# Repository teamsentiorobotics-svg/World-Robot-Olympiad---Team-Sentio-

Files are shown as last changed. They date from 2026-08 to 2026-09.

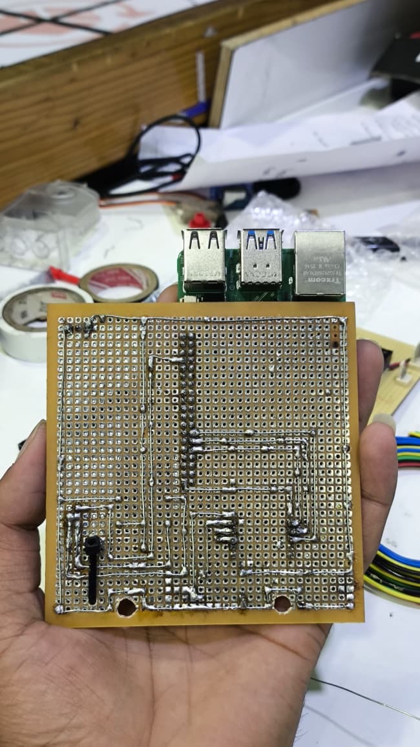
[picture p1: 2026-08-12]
v-photos/solder view of circuit board.jpg

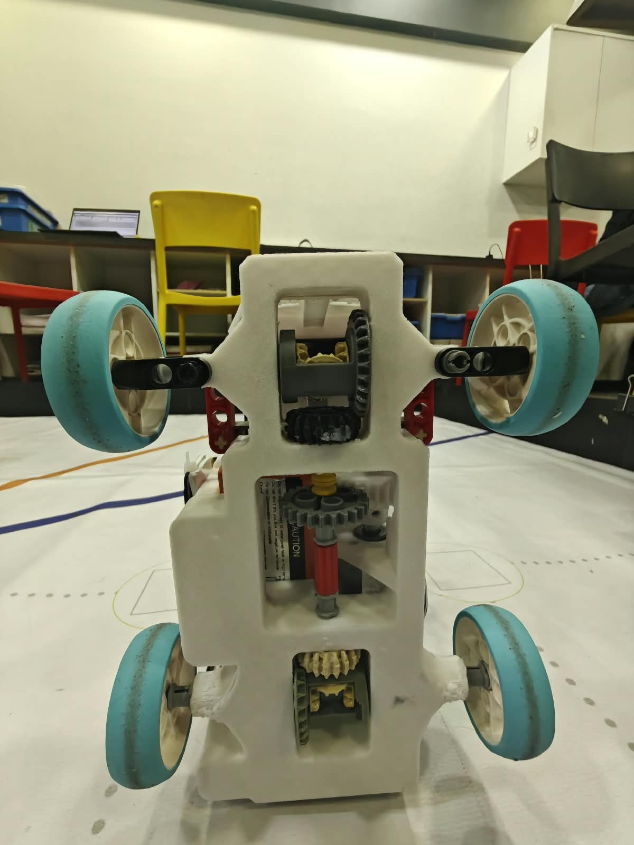
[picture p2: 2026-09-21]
v-photos/bottom view (1).jpg

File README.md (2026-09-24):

# Team Sentio - WRO Future Engineers 2026

> **Starlight**  
> Autonomous vehicle developed by **Team Sentio** for the **World Robot Olympiad 2026 - Future Engineers** category.

**Team:** Deyaan Agrawal, Darsh Zaveri, Aarav Jalan  
**Mentors:** Sunil Solanki, Shyam Satasiya  
**Institution / Training Environment:** Robofun Lab (RFL), India  
**Robot:** Starlight  
**Competition:** World Robot Olympiad 2026 - Future Engineers  
**Current Documentation Revision:** Revision 29, 23 September 2026

---

# Engineering Philosophy

Starlight was not developed as one finished design.

The vehicle evolved through repeated mechanical, electrical, sensing and software revisions.

Our development process follows:

> **Build → Test → Observe → Find the failure → Modify → Retest**

The current system combines:

- four-wheel drive;
- front Ackermann steering;
- a mechanical differential;
- dual Raspberry Pi Camera Module 3 Wide cameras;
- multi-ROI computer vision;
- HSV + LAB colour processing;
- an MPU6050 relative-heading reference;
- motor-encoder feedback;
- three VL53L0X time-of-flight sensors;
- modular Open, Obstacle and Parking controllers;
- Raspberry Pi 5 processing;
- field calibration and dedicated subsystem-test programs.

The project is documented as an integrated engineering system rather than as a collection of independent components.

---

# Repository Structure

```text
.
├── README.md
├── CHANGELOG.md
├── requirements.md
├── .gitattributes
├── .gitignore
│
├── src/
│   ├── Cal_APOC.py
│   ├── Final_Obstacle_Challenge.py
│   ├── N_Vision_final.py
│   ├── Sentio_Open_2026.py
│   ├── openvision.py
│   ├── TOF_22.py
│   ├── TUF_test.py
│   ├── drive.py
│   ├── encoder_test.py
│   ├── heading.py
│   ├── parking_final.py
│   └── servo_test.py
│
├── Models/
│
├── docs/
│   ├── BOM_purchase_links.md
│   ├── wiring_guide.md
│   ├── differential_drive_system.md
│   ├── Software_Dependencies.md
│   ├── pi_setup_instruction.md
│   │
│   ├── development/
│   │   └── apoc-hardware-update.md
│   │
│   ├── engineering_decisions/
│   ├── software/
│   ├── testing/
│   ├── failure_log.md
│   └── readme.md
│
├── schemes/
├── v-photos/
├── t-photos/
├── videos/
└── other/
```

| Location | Purpose |
|---|---|
| `src/` | Competition controllers, sensing modules, calibration tools and component tests |
| `Models/` | Chassis, robot-design and printable STL/CAD resources |
| `docs/` | Engineering decisions, testing records, BOM, wiring, dependencies and setup |
| `schemes/` | Electrical and wiring references |
| `v-photos/` | Vehicle photographs |
| `t-photos/` | Team photographs |
| `videos/` | Physical autonomous-driving evidence |
| `other/` | Supporting engineering, testing and planning material |
| `README.md` | Main repository-level project overview |
| `CHANGELOG.md` | Dated development history |
| `requirements.md` | Software dependency record |

---

# 1. System Overview

Starlight is a compact four-wheel autonomous vehicle designed around **car-like steering mechanics, camera-led navigation and multiple complementary sensors**.

The current configuration combines several different observations:

```text
CAMERAS
   ↓
Walls, pillars, track geometry and colour cues

MPU6050
   ↓
Relative heading and orientation change

MOTOR ENCODER
   ↓
Shaft rotation and movement feedback

3 × VL53L0X
   ↓
Short-range distance information

          ↓

     RASPBERRY PI 5

          ↓

Navigation state
Steering
Propulsion

          ↓

4WD + ACKERMANN STEERING
```

Each sensor answers a different question.

The software does not treat one sensor as an exact replacement for another.

---

# 2. Current Mechanical Architecture

The current vehicle uses:

- four-wheel drive;
- front Ackermann steering;
- a mechanical differential;
- custom structural components;
- LEGO Technic drivetrain and mechanism elements where appropriate;
- rigid camera supports;
- rigid distance-sensor mounts;
- a geared DC drive motor;
- quadrature encoder feedback.

The mechanical structure must do more than simply hold the robot together.

It must keep the following sufficiently repeatable:

- camera geometry;
- sensor direction;
- drivetrain alignment;
- steering geometry;
- electronics placement;
- mechanical clearances.

---

## Ackermann Steering

Starlight turns like a small car.

During a turn:

- the inside front wheel follows a smaller-radius path;
- the outside front wheel follows a larger-radius path;
- the inside wheel therefore requires a larger steering angle.

Ackermann geometry allows the two front wheels to approximately follow their respective turning paths rather than forcing them through identical angles.

This reduces tyre scrub and improves repeatability during curved motion.

---

## Mechanical Differential

Steering angle and driven-wheel speed solve different problems.

The outside driven wheel travels farther than the inside driven wheel during a turn.

The mechanical differential allows the two sides of the drivetrain to rotate at different speeds while remaining powered through the same transmission.

```text
ACKERMANN STEERING
→ sets wheel direction

MECHANICAL DIFFERENTIAL
→ permits unequal driven-wheel speeds
```

Both contribute to smoother car-like turning.

---

# 3. Drivetrain

The current drivetrain uses a:

```text
12 V geared DC encoder motor
Nominal output speed: 600 RPM
External gear ratio: 1:1
```

The final transmission intentionally uses a **1:1 external ratio**.

This replaced an earlier speed-increasing drivetrain configuration.

The revised design gives greater priority to:

- usable wheel torque;
- drivetrain reliability;
- controllable movement;
- reduced motor loading;
- repeatable challenge behaviour.

A nominal motor RPM is a component specification.

It should not automatically be interpreted as measured vehicle ground speed.

---

## Four-Wheel Drive

Motor rotation is transferred through the mechanical drivetrain to all four wheels.

Four-wheel drive was retained because it provides:

- improved traction;
- more consistent propulsion;
- better load distribution;
- greater reliability during steering and obstacle manoeuvres.

---

## Motor Encoder

The drive motor includes a quadrature encoder.

The encoder reports shaft motion and direction through pulses.

It is used for:

- movement feedback;
- drivetrain testing;
- encoder-controlled movement requests;
- checking motor response;
- repeatable motion during selected manoeuvres.

Encoder rotation is not identical to physical vehicle displacement.

Wheel slip, tyre deformation, drivetrain play and surface conditions can all cause body movement to differ from shaft-based estimates.

---

# 4. Main Electronics

The main computing platform is:

```text
Raspberry Pi 5
4 GB RAM
```

Current major hardware includes:

| Qty. | Component | Function |
|---:|---|---|
| 1 | Raspberry Pi 5, 4 GB | Main computer |
| 2 | Raspberry Pi Camera Module 3 Wide | Track and parking perception |
| 3 | VL53L0X ToF sensors | Short-range distance sensing |
| 1 | 12 V geared DC encoder motor, 600 RPM | Propulsion |
| 1 | Integrated quadrature encoder | Shaft-motion feedback |
| 1 | TB6612FNG motor driver | Motor direction and PWM |
| 1 | DS3225 digital servo | Ackermann steering |
| 1 | MPU6050-based heading sensor | Relative angular motion |
| 1 | 3S LiPo battery | Main energy source |
| 1 | Regulated Raspberry Pi supply | Computer power |
| 1 | Start button | Physical run input |
| 1 | Status / illumination LED | Indication and illumination |

---

# 5. Power System

Main battery:

```text
3S LiPo
11.1 V nominal
2200 mAh
```

Nominal stored energy:

```text
11.1 V × 2.2 Ah
≈ 24.42 Wh
```

Starlight separates the major electrical loads into functional branches.

```text
               BATTERY
                  │
         ┌────────┴────────┐
         │                 │
     MOTOR RAIL       REGULATED RAIL
         │                 │
   Motor driver        Raspberry Pi
   Drive motor         Cameras
                       Sensors
```

Connected control electronics share an appropriate common electrical reference.

Voltage stability is important because motor starts, motor reversals and servo movements can produce rapidly changing current demand.

---

# 6. GPIO and Interfaces

Main Raspberry Pi control assignments include:

| Function | BCM GPIO |
|---|---:|
| Motor IN1 | GPIO5 |
| Motor IN2 | GPIO6 |
| Motor PWM | GPIO13 |
| Steering servo | GPIO22 |
| Encoder A | GPIO17 |
| Encoder B | GPIO27 |
| I2C SDA | GPIO2 |
| I2C SCL | GPIO3 |
| ToF 1 XSHUT | GPIO16 |
| ToF 2 XSHUT | GPIO20 |
| ToF 3 XSHUT | GPIO21 |

The MPU6050 uses the shared I2C bus.

The three VL53L0X sensors also communicate over I2C.

Because identical VL53L0X sensors initially use the same default address, their XSHUT lines allow them to be enabled sequentially and assigned separate working addresses.

---

# 7. Camera Architecture

Starlight uses:

```text
2 × Raspberry Pi Camera Module 3 Wide
```

The camera arrangement is designed to observe the useful portion of the track while allowing different image regions to perform different tasks.

The documented viewing direction is approximately:

```text
60° from horizontal
```

The relatively downward-facing view prioritizes:

- nearby walls;
- pillar bases;
- track markers;
- parking geometry;
- immediate steering information.

The trade-off is reduced distant look-ahead and stronger perspective effects.

---

# 8. Multi-ROI Computer Vision

The current primary vision architecture uses a **720 × 360 image** divided into task-specific regions of interest.

A simplified representation is:

```text
┌──────────────────────────────────────────────┐
│ L1        L2        C        R2        R1    │
│                                              │
│            ORANGE / BLUE REGION              │
│                                              │
│              BODY EXCLUSION                  │
└──────────────────────────────────────────────┘
```

Different regions answer different navigation questions.

Responsibilities include:

- outer-wall observation;
- inner-wall observation;
- center reference;
- orange / blue course cues;
- pillar detection;
- robot-body exclusion.

The robot's own structure may appear dark in the camera image.

Body-exclusion regions prevent visible parts of the vehicle from being interpreted as track walls.

---

# 9. Vision Processing

The primary obstacle vision module is:

```text
src/N_Vision_final.py
```

The processing pipeline can be summarized as:

```text
Camera frame
     ↓
HSV / LAB conversion
     ↓
Task-specific ROI selection
     ↓
Colour / darkness thresholding
     ↓
Morphological filtering
     ↓
Contour extraction
     ↓
Area and geometry filtering
     ↓
Region-aware detection
     ↓
Navigation observation
```

The system uses combinations of:

- HSV colour information;
- LAB colour information;
- darkness information;
- contour size;
- contour geometry;
- image position;
- ROI identity.

Navigation therefore does not depend solely on whether a handful of pixels happen to match a colour threshold.

---

# 10. Calibration

Field lighting can substantially change the appearance of the same physical colour.

The repository therefore includes:

```text
src/Cal_APOC.py
```

This provides interactive LAB / HSV calibration controls.

Calibration is used to tune colour ranges for the actual competition environment before relying on those thresholds for autonomous navigation.

Calibration should be checked after changes involving:

- field lighting;
- camera position;
- camera angle;
- exposure;
- track material;
- major mechanical reconstruction.

---

# 11. Software Architecture

The competition software is divided into mission-level controllers and reusable hardware or sensing modules.

```text
                    VISION MODULES
                         │
             ┌───────────┴───────────┐
             │                       │
     Open Challenge           Obstacle Challenge
             │                       │
 Sentio_Open_2026.py     Final_Obstacle_Challenge.py
             │                       │
       openvision.py          N_Vision_final.py
             │                       │
             └───────────┬───────────┘
                         │
                  parking_final.py
                         │
                     heading.py
                         │
                      drive.py
                         │
               Motor + encoder
                 + steering
```

Distance-sensor support is provided through:

```text
TOF_22.py
```

This modular structure makes faults easier to isolate.

A poor autonomous turn may originate from:

- perception;
- target selection;
- heading estimation;
- steering;
- drivetrain response;
- state logic.

Separating these responsibilities allows individual layers to be tested before a complete challenge run.

---

# 12. Open Challenge

The current Open Challenge controller is:

```text
src/Sentio_Open_2026.py
```

Its dedicated vision module is:

```text
src/openvision.py
```

---

## Open Challenge Strategy

The Open Challenge primarily uses continuous wall-relative correction.

```text
Observe walls + course markers
            ↓
Determine course direction
            ↓
Select active wall reference
            ↓
Calculate image error
            ↓
Apply proportional steering
            ↓
Move
            ↓
Detect valid course event
            ↓
Repeat
```

A general proportional relationship is:

```text
steering request
=
center request
+
KP × image error
```

The controller repeatedly updates the steering response as camera observations change.

This differs from relying entirely on predetermined timed turns.

---

## Course Direction

Course direction affects:

- wall selection;
- target image position;
- fallback behaviour;
- obstacle context;
- parking approach.

---

## Course Event Counting

A physical marker can remain visible across many consecutive camera frames.

The controller therefore distinguishes:

```text
NEW EVENT
```

from:

```text
SAME EVENT STILL VISIBLE
```

Cooldown and transition logic prevent the same marker from being repeatedly counted simply because it remains visible.

---

# 13. Obstacle Challenge

The main controller is:

```text
src/Final_Obstacle_Challenge.py
```

The Obstacle Challenge combines:

- wall geometry;
- red pillar detection;
- green pillar detection;
- course direction;
- heading feedback;
- encoder-assisted movement;
- orange course-event counting;
- parking transition logic;
- repeated visual observations.

---

## Obstacle Selection

Red and green objects are treated as different navigation targets.

The controller considers:

- object colour;
- object position;
- bounding-box geometry;
- region identity;
- active manoeuvre;
- course direction.

A pillar becoming visible does not automatically mean that the robot should abandon an active manoeuvre.

This is especially important near corners, where a new observation may appear before the previous turn is complete.

---

## Continuous Perception

The obstacle architecture repeatedly returns to sensing.

```text
OBSERVE
   ↓
SELECT RELEVANT FEATURE
   ↓
CHOOSE ACTIVE CONTROL STATE
   ↓
STEER / MOVE
   ↓
OBSERVE AGAIN
```

The changing camera view is therefore part of the feedback loop.

---

# 14. MPU6050 Heading

Shared heading logic is contained in:

```text
src/heading.py
```

The heading module:

1. initializes communication with the MPU6050;
2. measures stationary gyro bias;
3. subtracts the estimated bias;
4. reads angular velocity;
5. integrates angular velocity over elapsed time;
6. maintains a relative heading estimate.

Conceptually:

```text
relative heading
=
previous heading
+
corrected angular velocity × elapsed time
```

The result is a **relative orientation estimate**.

It is not treated as an exact global compass or position measurement.

---

## Why Heading Feedback Is Useful

A fixed motor time does not always produce the same turn.

Variation can result from:

- battery condition;
- motor loading;
- tyre contact;
- friction;
- drivetrain resistance;
- surface conditions.

Heading feedback allows selected manoeuvres to finish according to the robot's observed orientation rather than time alone.

---

# 15. Parking

The parking controller is:

```text
src/parking_final.py
```

Parking combines:

- camera geometry;
- magenta parking references;
- wall observations;
- heading feedback;
- three VL53L0X distance sensors;
- forward and reverse Ackermann arcs;
- distance-confirmed stopping.

---

## Parking Objective

The final objective is to stop with the vehicle aligned **parallel to the magenta wall**.

Starlight cannot rotate about its center like a differential-drive robot.

Parking therefore requires controlled forward and reverse arcs.

---

## Parking Sequence

```text
COURSE COMPLETE
       ↓
IDENTIFY APPROACH DIRECTION
       ↓
POSITION VEHICLE
       ↓
ALIGN USING STEERING + HEADING
       ↓
READ SHORT-RANGE DISTANCE
       ↓
CONFIRM DISTANCE CONDITION
       ↓
FORWARD / REVERSE ADJUSTMENT
       ↓
FINAL PARALLEL ALIGNMENT
       ↓
STOP
```

The range sensors complement the camera and heading system.

They do not replace them.

```text
CAMERA
→ Where is the feature?

HEADING
→ Which direction is the robot pointing?

ToF
→ How large is the nearby gap?

ENCODER
→ How much shaft movement occurred?
```

---

# 16. ToF Distance Sensing

The current vehicle uses:

```text
3 × VL53L0X
```

The main distance-sensor support module is:

```text
src/TOF_22.py
```

The repository also includes:

```text
src/TUF_test.py
```

for standalone sensor testing.

The distance-sensor system supports:

- XSHUT activation sequencing;
- unique I2C addressing;
- repeated distance measurements;
- qualifying-distance thresholds;
- confirmation instead of trusting one isolated reading;
- cooldown between qualifying detections;
- range-based movement termination;
- parking alignment and clearance checks.

---

# 17. Clockwise and Anticlockwise Parking

The two possible course directions require different paths into the parking area.

```text
                    COURSE COMPLETE
                          │
                 Determine direction
                    ┌─────┴─────┐
                    │           │
                   CW          ACW
                    │           │
          CW entry position   Reposition
                    │           │
                    │       Follow wall
                    │           │
                    │     Opposite corner
                    └─────┬─────┘
                          │
                Shared final parking
                          │
               Parallel to magenta wall
                          │
                         STOP
```

The anticlockwise path performs the required repositioning before joining the final parking sequence.

---

# 18. Component Test Programs

Full challenge runs are not the first debugging step.

The repository contains dedicated subsystem tests.

---

## Steering Test

```text
src/servo_test.py
```

Used to verify:

- steering direction;
- center position;
- steering range;
- mechanical clearance;
- linkage behaviour.

---

## Encoder Test

```text
src/encoder_test.py
```

Used to verify:

- encoder pulse response;
- direction;
- motor movement;
- encoder-based drive control.

---

## Distance Sensor Test

```text
src/TUF_test.py
```

Used to verify:

- VL53L0X initialization;
- XSHUT sequencing;
- unique sensor addressing;
- distance readings;
- sensor orientation.

---

## Vision Calibration

```text
src/Cal_APOC.py
```

Used to tune:

- HSV thresholds;
- LAB thresholds;
- field colour appearance.

---

# 19. Testing Workflow

Team Sentio uses a layered validation process.

```text
COMPONENT TEST
      ↓
SUBSYSTEM TEST
      ↓
LOW-SPEED INTEGRATED TEST
      ↓
FULL CHALLENGE RUN
      ↓
OBSERVE FAILURE
      ↓
IDENTIFY RESPONSIBLE LAYER
      ↓
MODIFY
      ↓
RETEST
```

Before a complete autonomous run, checks include:

- battery state;
- electrical connections;
- regulated Raspberry Pi supply;
- common electrical reference;
- motor direction;
- drivetrain freedom;
- gear engagement;
- steering linkage;
- steering limits;
- encoder response;
- camera operation;
- vision calibration;
- MPU6050 communication;
- ToF communication;
- ToF sensor orientation;
- correct source-code revision.

---

# 20. Physical Timing Records

The engineering record retains successful-run timing observations from development and practice.

```text
Development cohort: 19 successful runs
Practice cohort:    12 successful runs
```

| Cohort | n | Mean | Median | SD | Range |
|---|---:|---:|---:|---:|---:|
| Development | 19 | 25.05 s | 23 s | 5.74 s | 18-37 s |
| Practice | 12 | 23.00 s | 23 s | 1.28 s | 21-25 s |

These are **successful retained runs only**.

They are not presented as the success rate of all attempted runs.

Different runs also belong to changing development configurations, so these timings should not be interpreted as a controlled comparison of one isolated design change.

---

# 21. Nationals Competition Record

The Nationals results belong to an **earlier competition configuration** and should not be interpreted as measurements of the current post-Nationals APOC revision.

| Round | Recorded Score | Recorded Time | Recorded Outcome |
|---|---:|---:|---|
| Open Run 1 | 0 / 30 | - | Inner-wall contact interrupted run |
| Open Run 2 | 30 / 30 | 56 s | Completed clockwise course |
| Obstacle Run 2 | 29 / 62 | 66 s to stop | Green-obstacle contact, parking not achieved |

These competition outcomes influenced later redesign of:

- camera geometry;
- vision regions;
- drivetrain;
- sensing;
- obstacle behaviour;
- parking logic.

---

# 22. Post-Nationals / APOC Redesign

The September 2026 configuration is a new engineering revision rather than a retroactive description of the Nationals vehicle.

Major changes include:

- revised chassis;
- revised camera placement;
- rigid sensing geometry;
- dual Camera Module 3 Wide architecture;
- multi-ROI vision;
- explicit body-exclusion regions;
- LAB / HSV calibration tools;
- revised wall detection;
- revised pillar detection;
- revised Open Challenge controller;
- revised Obstacle Challenge controller;
- three VL53L0X distance sensors;
- encoder-assisted movement;
- revised parking-distance logic;
- 600 RPM motor;
- 1:1 external drivetrain ratio.

---

# 23. Important Engineering Decisions

| Engineering Decision | Reason |
|---|---|
| Four-wheel drive | Improved propulsion consistency and traction |
| Ackermann steering | Car-like turning geometry |
| Mechanical differential | Allows unequal driven-wheel speeds during turns |
| 600 RPM encoder motor | Balance of movement, torque and controllability |
| 1:1 external gearing | Retains more wheel torque than the earlier speed-increasing stage |
| Rigid camera supports | More repeatable visual geometry |
| Approx. 60° camera view | Emphasizes nearby track features |
| Multi-ROI vision | Gives different image regions specific jobs |
| Body exclusion | Prevents the robot from detecting itself as a wall |
| HSV + LAB calibration | Field-specific colour adjustment |
| MPU6050 heading | Orientation-sensitive manoeuvre feedback |
| Encoder feedback | Shaft-motion information |
| Three VL53L0X sensors | Close-range gap and parking information |
| Modular software | Easier debugging and replacement of subsystems |
| Component-test scripts | Fault isolation before complete autonomous runs |

---

# 24. CAD and Mechanical Files

Mechanical-design resources are stored in:

```text
Models/
```

The directory contains available Starlight CAD, printable and mechanical-design resources.

Earlier CAD and prototype material is intentionally retained where useful for documenting the development process.

Earlier models should not automatically be interpreted as the exact geometry of the current robot.

---

# 25. Electrical Documentation

Electrical and wiring information is contained primarily in:

```text
docs/
schemes/
```

Important documents include:

```text
docs/BOM_purchase_links.md
docs/wiring_guide.md
docs/Software_Dependencies.md
docs/pi_setup_instruction.md
```

Together these document:

```text
COMPONENTS
     +
POWER / SIGNAL CONNECTIONS
     +
GPIO ASSIGNMENTS
     +
SOFTWARE CONTROL
```

A reproducible robot requires all four.

---

# 26. Engineering Development Records

The repository also preserves development evidence.

Relevant areas include:

```text
docs/development/
docs/engineering_decisions/
docs/testing/
docs/failure_log.md
CHANGELOG.md
```

These records document:

- hardware changes;
- observed failures;
- diagnoses;
- design decisions;
- corrective changes;
- retesting;
- configuration evolution.

The objective is to preserve not only what worked, but also **why the final design became different from earlier versions**.

---

# 27. Raspberry Pi Setup

Detailed setup information is provided through:

```text
docs/pi_setup_instruction.md
docs/Software_Dependencies.md
requirements.md
```

The software stack includes technologies such as:

- Python 3;
- OpenCV;
- NumPy;
- Picamera2;
- Raspberry Pi GPIO support;
- I2C / SMBus interfaces;
- GPIO Zero where required;
- sensor-specific Python libraries used by the robot.

The environment should be prepared before attempting to run competition controllers.

---

# 28. Recommended Reproduction Workflow

```text
1. Review README.md
        ↓
2. Review BOM and wiring
        ↓
3. Review Models/
        ↓
4. Assemble mechanical system
        ↓
5. Install Raspberry Pi environment
        ↓
6. Connect electronics
        ↓
7. Verify steering
        ↓
8. Verify motor + encoder
        ↓
9. Verify cameras
        ↓
10. Verify MPU6050
        ↓
11. Verify all VL53L0X sensors
        ↓
12. Calibrate vision
        ↓
13. Run low-speed integration
        ↓
14. Run challenge controller
        ↓
15. Record software + hardware revision
```

A challenge result should remain associated with the exact:

- hardware arrangement;
- camera geometry;
- calibration;
- software revision;
- observed result.

---

# 29. Current Competition Software

```text
src/
├── Cal_APOC.py
├── Final_Obstacle_Challenge.py
├── N_Vision_final.py
├── Sentio_Open_2026.py
├── openvision.py
├── TOF_22.py
├── TUF_test.py
├── drive.py
├── encoder_test.py
├── heading.py
├── parking_final.py
└── servo_test.py
```

### `Cal_APOC.py`

Interactive LAB / HSV field-calibration tool.

### `Final_Obstacle_Challenge.py`

Main Obstacle Challenge controller.

### `N_Vision_final.py`

Final multi-ROI computer vision for walls, pillars and track colours.

### `Sentio_Open_2026.py`

Main Open Challenge controller.

### `openvision.py`

Dedicated Open Challenge vision module.

### `TOF_22.py`

Three-sensor VL53L0X initialization and distance interface.

### `TUF_test.py`

Distance-sensor test program.

### `drive.py`

Motor, encoder and steering interface.

### `encoder_test.py`

Encoder and motor-control test program.

### `heading.py`

Shared MPU6050 relative-heading estimator.

### `parking_final.py`

Direction-dependent parking and final parking control.

### `servo_test.py`

Steering direction, center and range testing.

---

# 30. Development History

Starlight progressed through multiple complete vehicle configurations.

| Stage | Main Development |
|---|---|
| Early LEGO platform | Wheel motion, steering and basic structure |
| Hybrid construction | LEGO mechanisms combined with printed supports |
| Nationals configuration | Integrated navigation, obstacle response and parking |
| Post-Nationals redesign | New chassis, camera geometry, vision regions and sensing |
| Current APOC configuration | Multi-ROI perception, encoder feedback and three-ToF architecture |

The important point is that improvements were not isolated.

Changing one subsystem changed the conditions faced by others.

```text
CAMERA POSITION
→ changes image geometry

MOTOR / GEARING
→ changes movement response

STEERING
→ changes the path produced by the same command

POWER
→ changes computer and actuator reliability

SOFTWARE
→ must respond to all of the above
```

The robot therefore evolved as a complete system.

---

# 31. Team Contributions

## Deyaan Agrawal

Primary areas included:

- software;
- autonomous algorithms;
- navigation logic;
- debugging;
- tuning;
- track testing.

## Darsh Zaveri

Primary areas included:

- hardware;
- LEGO mechanisms;
- mechanical assembly;
- circuits;
- wiring;
- drivetrain;
- physical troubleshooting;
- testing.

## Aarav Jalan

Primary areas included:

- CAD;
- algorithm contributions;
- custom structures;
- circuits;
- system integration;
- engineering documentation;
- technical records.

---

# 32. Mentors and Robofun Lab

### Sunil Solanki

Technical guidance, testing support and design review.

### Shyam Satasiya

Technical guidance, testing support and design review.

Robofun Lab provided the environment, facilities and technical guidance used during development and testing.

The robot, source code, design decisions, testing process and engineering record remain the work of **Team Sentio**.

---

# 33. Evidence Philosophy

The project distinguishes between several types of engineering evidence.

### Recorded observation

Something physically observed during development, testing or competition.

### Specification

A manufacturer or configuration value associated with a component.

### Calculation

A result mathematically derived from stated inputs and assumptions.

### Computer study

A result generated using a simplified numerical or computational model.

These categories should not be treated as interchangeable.

For example:

```text
600 RPM
```

is a motor specification.

It is not automatically the measured wheel speed of the robot.

Likewise, an encoder count describes shaft motion and is not automatically exact ground displacement.

---

# 34. Repository Synchronization

The repository should remain synchronized with the software physically running on Starlight.

The active Git revision can be checked using:

```bash
git rev-parse HEAD
```

Calibration or controller changes should be physically tested before being treated as a new final competition configuration.

A useful run record should identify:

```text
Hardware configuration
+
Camera arrangement
+
Calibration
+
Software revision
+
Observed result
```

Without those together, reproducing a result becomes guesswork.

---

# 35. Final Pre-Run Checklist

Before an official run:

- [ ] Correct Git/software revision loaded
- [ ] Battery checked
- [ ] Raspberry Pi supply stable
- [ ] Motor and drivetrain free
- [ ] Steering centered and mechanically clear
- [ ] Encoder responding
- [ ] Both cameras detected
- [ ] Camera exposure checked
- [ ] HSV / LAB calibration completed
- [ ] MPU6050 calibration completed while stationary
- [ ] Three VL53L0X sensors detected
- [ ] ToF addresses correct
- [ ] ToF orientations correct
- [ ] Open controller tested
- [ ] Obstacle controller tested
- [ ] Parking sequence tested
- [ ] Clockwise course tested
- [ ] Anticlockwise course tested
- [ ] Course-event cooldown logic checked
- [ ] Final parking stop logic checked
- [ ] No loose wires or mechanical interference
- [ ] Correct files committed to GitHub

---

# Final Engineering Principle

Starlight was not created by getting every design choice correct on the first attempt.

The project progressed through:

- drivetrain problems;
- steering changes;
- camera-position experiments;
- colour-detection errors;
- power issues;
- obstacle-navigation failures;
- parking experiments;
- mechanical redesigns;
- sensor additions;
- repeated software tuning.

Each failure supplied information for the next revision.

> **Dream. Design. Build. Test. Fail. Understand. Improve. Repeat.**

---

**Team Sentio**  
**Starlight**  
**World Robot Olympiad - Future Engineers 2026**  
**Robofun Lab (RFL), India**

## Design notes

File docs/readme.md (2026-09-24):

# Starlight Technical Documentation

**Team Sentio 6010**  
**WRO Future Engineers 2026**  
**Robot:** Starlight  
**Organisation:** Robofun Lab (RFL), India

---

## Documentation Overview

This directory contains the technical documentation for **Starlight**, Team Sentio's autonomous vehicle developed for the **World Robot Olympiad 2026 Future Engineers** category.

**Current documentation baseline:** Engineering Journal Revision 29.

The documentation is organized around the complete engineering process:

```text
Requirement
    ↓
Design
    ↓
Prototype
    ↓
Test
    ↓
Observe
    ↓
Identify limitation
    ↓
Modify
    ↓
Retest
    ↓
Retain / Reject
```

The aim is not only to describe the final robot, but also to make the development process traceable:

- what was built;
- why major decisions were made;
- what failed;
- what changed;
- how changes were tested;
- which configuration is current;
- how the system can be reproduced.

---

# Quick Navigation

## Engineering Process

| Document | Purpose |
| --- | --- |
| [Engineering Decisions](engineering-decisions.md) | Major design decisions, alternatives considered, trade-offs and reasons for the retained architecture |
| [Failure Log](failure-log.md) | Observed failures, diagnoses, engineering responses and retest outcomes |
| [Testing](testing.md) | Structured component, subsystem and integrated testing records |

These three documents form the main engineering traceability chain:

```text
Why was it chosen?
        ↓
engineering-decisions.md

What went wrong?
        ↓
failure-log.md

How was it verified?
        ↓
testing.md
```

---

# Hardware Documentation

| Document | Purpose |
| --- | --- |
| [Bill of Materials](hardware/bom.md) | Current components, specifications and sourcing references |
| [Drivetrain](hardware/drivetrain.md) | 4WD architecture, 1:1 gearing, motor, encoder, differential and Ackermann steering |
| [Wiring Guide](hardware/wiring-guide.md) | GPIO assignments, power connections, motor control, I2C and sensor wiring |

---

## Current Hardware Architecture

The current **Revision 29** Starlight configuration includes:

- Raspberry Pi 5, 4 GB;
- 2 × Raspberry Pi Camera Module 3 Wide;
- 3 × VL53L0X Time-of-Flight sensors;
- MPU6050 heading sensor;
- 12 V, 600 RPM geared DC motor;
- integrated quadrature encoder;
- TB6612FNG motor driver;
- DS3225 steering servo;
- four-wheel drive;
- mechanical differential;
- front Ackermann steering;
- 1:1 external drivetrain gearing.

The current configuration combines visual, heading, shaft-motion and distance observations rather than relying on a single sensing method.

```text
CAMERAS
   ↓
Appearance + geometry

MPU6050
   ↓
Relative heading

ENCODER
   ↓
Shaft movement

3 × ToF
   ↓
Local physical distance

        ↓
AUTONOMOUS CONTROL
```

---

# Software Documentation

| Document | Purpose |
| --- | --- |
| [Software Dependencies](software/Software_Dependencies.md) | Python environment, external packages, module relationships and reproducibility checks |
| [Raspberry Pi Setup](software/pi_setup_instruction.md) | Raspberry Pi installation, interface setup and system preparation |

The current principal source files are located in:

```text
../src/
```

and include:

```text
Cal_APOC.py
Final_Obstacle_Challenge.py
N_Vision_final.py
Sentio_Open_2026.py
openvision.py
TOF_22.py
TUF_test.py
drive.py
encoder_test.py
heading.py
parking_final.py
servo_test.py
```

The Revision 29 source map explicitly includes:

- `drive.py` as the shared motor, steering and encoder interface;
- `TOF_22.py` as the three-VL53L0X sensor interface;
- `TUF_test.py`, `encoder_test.py` and `servo_test.py` as dedicated subsystem tests.

Every local module required by the physically tested competition controllers should also be present in GitHub.

---

# Development History

| Document | Purpose |
| --- | --- |
| [APOC Hardware Update](development/apoc-hardware-update.md) | Post-Nationals chassis, camera, drivetrain and sensor redesign for the Asia Pacific Open Championship |

The current robot is the result of several major development stages:

```text
Early LEGO platform
        ↓
Hybrid LEGO + printed construction
        ↓
Nationals configuration
        ↓
Post-Nationals redesign
        ↓
Current APOC-oriented architecture
```

The post-Nationals redesign revised the:

- chassis;
- camera locations;
- camera mounts;
- vision geometry;
- drivetrain operating point;
- encoder integration;
- distance sensing;
- parking architecture.

---

# Current Design Identity

Starlight combines several mechanical and sensing decisions into one vehicle architecture.

| Design Feature | Engineering Purpose |
| --- | --- |
| **4WD** | Distribute propulsion across four driven wheels |
| **Ackermann steering** | Produce car-like forward and reverse turning geometry |
| **Mechanical differential** | Allow driven wheels to rotate at different speeds during a turn |
| **600 RPM encoder motor** | Provide propulsion with shaft-motion feedback |
| **1:1 gearing** | Prioritize available torque and controllability over maximum theoretical speed |
| **Dual cameras** | Provide task-specific visual geometry |
| **Multi-ROI vision** | Assign different image regions to different navigation tasks |
| **MPU6050** | Provide relative-heading feedback |
| **3 × VL53L0X** | Measure local physical gaps during close-range manoeuvres |
| **Rigid sensor mounts** | Preserve calibration geometry |

---

# Engineering Traceability

The documentation is designed so that a major design change can be traced across several files.

For example:

```text
Observed drivetrain stall
        ↓
failure-log.md
        ↓
Motor / gearing reconsidered
        ↓
engineering-decisions.md
        ↓
600 RPM motor + 1:1 gearing
        ↓
hardware/drivetrain.md
        ↓
encoder / drivetrain testing
        ↓
testing.md
```

Another example:

```text
Parking inconsistency
        ↓
failure-log.md
        ↓
Need direct gap information
        ↓
engineering-decisions.md
        ↓
3 × VL53L0X added
        ↓
development/apoc-hardware-update.md
        ↓
parking / ToF trials
        ↓
testing.md
```

This prevents the repository from presenting the final robot as if every design choice mysteriously appeared fully formed.

---

# Documentation Structure

Recommended `docs/` structure:

```text
docs/
├── README.md
├── engineering-decisions.md
├── failure-log.md
├── testing.md
│
├── hardware/
│   ├── bom.md
│   ├── drivetrain.md
│   └── wiring-guide.md
│
├── software/
│   ├── Software_Dependencies.md
│   └── pi_setup_instruction.md
│
└── development/
    └── apoc-hardware-update.md
```

---

# Repository Structure

The complete project extends beyond this documentation directory.

```text
World-Robot-Olympiad---Team-Sentio-/
│
├── README.md
├── CHANGELOG.md
│
├── src/
│   ├── Cal_APOC.py
│   ├── Final_Obstacle_Challenge.py
│   ├── N_Vision_final.py
│   ├── Sentio_Open_2026.py
│   ├── openvision.py
│   ├── TOF_22.py
│   ├── TUF_test.py
│   ├── drive.py
│   ├── encoder_test.py
│   ├── heading.py
│   ├── parking_final.py
│   └── servo_test.py
│
├── docs/
│   ├── engineering documentation
│   ├── testing
│   ├── hardware
│   ├── software
│   └── development history
│
├── Models/
│   ├── CAD
│   └── printable parts
│
├── schemes/
│   └── electrical documentation
│
├── v-photos/
│   └── vehicle and development photographs
│
├── t-photos/
│   └── team photographs
│
└── videos/
    └── autonomous demonstration evidence
```

---

# Suggested Judge Route

For a rapid technical review, the most useful path through the repository is:

### 1. Understand the final robot

Start with:

- [`../README.md`](../README.md)
- [`hardware/drivetrain.md`](hardware/drivetrain.md)
- [`hardware/bom.md`](hardware/bom.md)

---

### 2. Understand why the design looks this way

Read:

- [`engineering-decisions.md`](engineering-decisions.md)
- [`development/apoc-hardware-update.md`](development/apoc-hardware-update.md)

---

### 3. See the engineering iteration

Read:

- [`failure-log.md`](failure-log.md)

This records the progression from:

```text
Failure
   ↓
Diagnosis
   ↓
Engineering change
   ↓
Retest
```

---

### 4. Check the evidence

Read:

- [`testing.md`](testing.md)

This contains the component and integrated testing records supporting the retained architecture.

---

### 5. Inspect the implementation

Continue to:

```text
../src/
```

for the current competition code.

---

# Hardware → Software Relationship

Starlight is documented as one connected system.

A physical change can affect the software directly.

```text
Camera position changes
        ↓
Image geometry changes
        ↓
ROI coordinates change
        ↓
Detection changes
        ↓
Steering decision changes
```

Likewise:

```text
Motor / gearing changes
        ↓
Acceleration and movement change
        ↓
Camera scene changes faster/slower
        ↓
Control timing changes
        ↓
Stopping geometry changes
```

For this reason, mechanics, electronics and software are not documented as independent projects.

---

# Evidence Categories

The documentation distinguishes four kinds of evidence.

| Type | Meaning |
| --- | --- |
| **Recorded observation** | Behaviour observed during physical development or competition |
| **Specification** | Manufacturer rating or retained robot configuration |
| **Calculation** | Result derived from stated inputs and assumptions |
| **Computer study** | Result from a simplified numerical or simulated model |

These categories should not be mixed.

For example:

```text
600 RPM
```

is a motor specification.

```text
1.445 m/s
```

is an ideal calculated wheel-speed conversion for the current 1:1 drivetrain and 46 mm wheels.

Neither should automatically be described as a measured track speed.

---

# Testing Philosophy

Starlight is tested from the component level upward.

```text
Component
    ↓
Subsystem
    ↓
Integrated behaviour
    ↓
Complete challenge
```

Typical checks include:

- steering direction and travel;
- encoder response;
- motor operation;
- heading calibration;
- VL53L0X communication;
- camera calibration;
- colour separation;
- parking transitions;
- complete Open Challenge runs;
- complete Obstacle Challenge runs.

A successful component test does not automatically prove the complete robot will succeed.

Likewise, a successful complete run does not prove that every subsystem has a quantified reliability percentage.

---

# Reproducibility Principle

The project follows this rule:

```text
Physical robot
      =
Raspberry Pi source
      =
GitHub source
      =
Documentation
```

A competition result is meaningful only when the hardware and software configuration that produced it can be identified.

Before a final competition release:

```bash
git status
```

should not reveal undocumented source changes that exist only on the robot.

The tested revision can be recorded with:

```bash
git rev-parse HEAD
```

---

# Current Configuration vs Historical Material

The repository intentionally retains earlier:

- CAD;
- photographs;
- gearing calculations;
- motor references;
- software;
- test records.

These show engineering development.

However, historical information must be clearly labelled.

The current **Revision 29** configuration uses:

```text
600 RPM encoder motor
1:1 external gearing
4WD
Ackermann steering
mechanical differential
2 wide cameras
3 VL53L0X sensors
MPU6050
encoder feedback
multi-ROI vision
```

Older speed-increasing drivetrain configurations or previous camera layouts should not be interpreted as the current competition robot.

---

# Core Documentation Map

| Engineering Question | Where to Look |
| --- | --- |
| **What is Starlight?** | [`../README.md`](../README.md) |
| **Why was this design chosen?** | [`engineering-decisions.md`](engineering-decisions.md) |
| **What failed during development?** | [`failure-log.md`](failure-log.md) |
| **How was it tested?** | [`testing.md`](testing.md) |
| **How does the drivetrain work?** | [`hardware/drivetrain.md`](hardware/drivetrain.md) |
| **What hardware is installed?** | [`hardware/bom.md`](hardware/bom.md) |
| **How is it wired?** | [`hardware/wiring-guide.md`](hardware/wiring-guide.md) |
| **What changed for APOC?** | [`development/apoc-hardware-update.md`](development/apoc-hardware-update.md) |
| **What software is required?** | [`software/Software_Dependencies.md`](software/Software_Dependencies.md) |
| **How is the Raspberry Pi configured?** | [`software/pi_setup_instruction.md`](software/pi_setup_instruction.md) |
| **Where is the robot code?** | [`../src/`](../src/) |
| **Where are the CAD files?** | [`../Models/`](../Models/) |
| **Where are robot photographs?** | [`../v-photos/`](../v-photos/) |
| **Where is video evidence?** | [`../videos/`](../videos/) |

---

# Engineering Principle

Starlight was developed around a simple rule:

> **Do not document only what the robot became. Document why it became that way.**

A strong engineering record should connect:

```text
Problem
   ↓
Evidence
   ↓
Decision
   ↓
Implementation
   ↓
Test
   ↓
Result
```

That relationship is the purpose of this documentation directory.

---

**Team Sentio 6010**  
**Starlight**  
**World Robot Olympiad - Future Engineers 2026**  
**Robofun Lab (RFL), India**

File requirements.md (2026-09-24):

# Software Requirements

## Team Sentio — WRO Future Engineers 2026

This document records the software environment, dependencies, hardware interfaces and verification process required to reproduce and run **Team Sentio's autonomous vehicle, Starlight**.

**Platform:** Raspberry Pi 5, 4 GB  
**Operating System:** Raspberry Pi OS  
**Programming Language:** Python 3  
**Competition:** World Robot Olympiad 2026 — Future Engineers  
**Robot:** Starlight  
**Current Documentation Baseline:** Engineering Journal Revision 29

The current Revision 29 Starlight configuration uses:

- dual Raspberry Pi Camera Module 3 Wide cameras;
- multi-ROI computer vision;
- MPU6050 heading feedback;
- a quadrature motor encoder;
- three VL53L0X time-of-flight sensors;
- Ackermann steering;
- four-wheel drive;
- modular Open, Obstacle and Parking controllers.

This document should remain synchronized with the exact software physically running on the competition robot.

For complete Raspberry Pi setup instructions, see:

[`docs/pi_setup_instruction.md`](docs/pi_setup_instruction.md)

---

# 1. Current Competition Software

The current competition software architecture is organized around:

```text
src/
├── Cal_APOC.py
├── Final_Obstacle_Challenge.py
├── N_Vision_final.py
├── Sentio_Open_2026.py
├── openvision.py
├── TOF_22.py
├── TUF_test.py
├── drive.py
├── encoder_test.py
├── heading.py
├── parking_final.py
└── servo_test.py
```

The current low-level drive interface is `src/drive.py`, and the current three-sensor ToF interface is `src/TOF_22.py`.

Every local module imported by the physically tested competition controllers must be present in `src/` or otherwise clearly documented as an external dependency.

| File | Purpose |
|---|---|
| `src/N_Vision_final.py` | Final multi-ROI computer vision for walls, pillars and course colours |
| `src/Final_Obstacle_Challenge.py` | Main Obstacle Challenge controller |
| `src/Sentio_Open_2026.py` | Main Open Challenge controller |
| `src/openvision.py` | Primary Open Challenge vision module |
| `src/TOF_22.py` | Three-VL53L0X initialization, XSHUT sequencing and distance interface |
| `src/drive.py` | Motor PWM, motor direction, steering and encoder-assisted movement interface |
| `src/parking_final.py` | Direction-dependent parking entry and final parallel-parking routine |
| `src/heading.py` | MPU6050 calibration and relative heading calculation |
| `src/Cal_APOC.py` | LAB / HSV field-calibration tool |
| `src/servo_test.py` | Steering direction, center and travel testing |
| `src/encoder_test.py` | Motor-encoder and movement-control testing |
| `src/TUF_test.py` | Three-sensor VL53L0X distance-system testing |

The final repository must also contain every local module imported by these programs.

A file that exists only on the Raspberry Pi but is missing from GitHub makes the repository incomplete.

---

# 2. Software Architecture

The current architecture separates:

```text
PERCEPTION
    ↓
STATE / NAVIGATION
    ↓
MOTION REQUEST
    ↓
DRIVE + STEERING
```

Sensor information comes from:

```text
DUAL CAMERAS
→ walls, pillars, track colours and parking geometry

MPU6050
→ relative heading

MOTOR ENCODER
→ shaft rotation and movement feedback

3 × VL53L0X
→ short-range distance information
```

These observations are combined by the challenge controllers.

---

# 3. Open Challenge Architecture

The current Open Challenge controller is:

```text
src/Sentio_Open_2026.py
```

Its primary vision module is:

```text
src/openvision.py
```

The complete multi-ROI module:

```text
src/N_Vision_final.py
```

can also provide compatible visual information where used by the current controller.

Conceptual dependency structure:

```text
Sentio_Open_2026.py
│
├── openvision.py
│   ├── OpenCV
│   ├── NumPy
│   └── Picamera2
│
├── drive.py
│   ├── motor control
│   ├── steering control
│   └── encoder feedback
│
└── course-state logic
```

The Open Challenge uses vision to determine:

```text
BLACK WALL GEOMETRY
BLUE COURSE CUES
ORANGE COURSE CUES
```

The controller repeatedly observes the track and applies wall-relative steering corrections.

Course-marker logic is also used to:

- establish direction;
- track course progress;
- prevent one visible marker from being counted repeatedly;
- determine completion of the required sequence.

---

# 4. Obstacle Challenge Architecture

The current Obstacle Challenge controller is:

```text
src/Final_Obstacle_Challenge.py
```

Conceptual dependency structure:

```text
Final_Obstacle_Challenge.py
│
├── N_Vision_final.py
│   ├── OpenCV
│   ├── NumPy
│   └── Picamera2
│
├── heading.py
│   └── MPU6050
│
├── drive.py
│   ├── motor control
│   ├── encoder
│   └── steering
│
└── parking_final.py
    ├── cameras
    ├── heading.py
    ├── TOF_22.py
    └── drive.py
```

The Obstacle Challenge combines:

```text
RED PILLARS
GREEN PILLARS
BLACK WALLS
BLUE COURSE CUES
ORANGE COURSE CUES
MAGENTA PARKING FEATURES
```

with:

```text
COURSE DIRECTION
HEADING
ENCODER MOVEMENT
PARKING STATE
```

The final behaviour is based on repeated sensing and state-dependent movement rather than one fixed sequence of timed turns.

---

# 5. Core Software Dependencies

| Dependency | Purpose |
|---|---|
| **Python 3** | Executes competition software |
| **OpenCV (`cv2`)** | Image processing, masking, morphology and contour analysis |
| **NumPy** | Image-array and numerical operations |
| **Picamera2** | Raspberry Pi Camera Module interface |
| **RPi.GPIO-compatible interface** | Motor, steering and other GPIO control |
| **SMBus / SMBus2** | I2C communication where used by heading and sensors |
| **VL53L0X-compatible Python interface** | Distance-sensor communication |

The exact package used for the final VL53L0X implementation must match the imports contained in the physically tested `TOF_22.py`, `TUF_test.py` and parking source.

Dependencies should not be added merely because they were used during experimentation.

Only software required by the submitted project should be listed as a competition dependency.

---

# 6. Raspberry Pi OS Packages

Begin with:

```bash
sudo apt update
sudo apt upgrade -y
```

Install the main Raspberry Pi software dependencies:

```bash
sudo apt install -y \
    git \
    python3-picamera2 \
    python3-opencv \
    python3-numpy \
    python3-smbus2 \
    i2c-tools
```

Additional Python packages required by the final VL53L0X implementation should be installed according to the imports used by the committed sensor source.

---

# 7. GPIO Support on Raspberry Pi 5

The drive software uses the Raspberry Pi GPIO interface.

Verify that the required namespace is available:

```bash
python3 -c "import RPi.GPIO as GPIO; print('GPIO import OK')"
```

On Raspberry Pi 5 systems where a compatible implementation is not already available:

```bash
sudo apt install -y python3-rpi-lgpio
```

If a conflicting classic implementation is installed:

```bash
sudo apt remove -y python3-rpi.gpio
sudo apt install -y python3-rpi-lgpio
```

Verify again:

```bash
python3 -c "import RPi.GPIO as GPIO; print('GPIO interface OK')"
```

The exact GPIO behaviour must match the software that was physically tested on Starlight.

---

# 8. Main GPIO Architecture

The published Starlight hardware baseline uses BCM numbering.

| Function | BCM GPIO |
|---|---:|
| Motor direction IN1 | GPIO5 |
| Motor direction IN2 | GPIO6 |
| Motor PWM | GPIO13 |
| Steering servo PWM | GPIO22 |
| Encoder A | GPIO17 |
| Encoder B | GPIO27 |
| I2C SDA | GPIO2 |
| I2C SCL | GPIO3 |
| ToF 1 XSHUT | GPIO16 |
| ToF 2 XSHUT | GPIO20 |
| ToF 3 XSHUT | GPIO21 |

The final source remains authoritative for any additional pins associated with:

- start button;
- status LED;
- auxiliary control lines.

Do not copy a GPIO assignment from an earlier robot revision without checking the final source.

---

# 9. Three VL53L0X Sensors

Starlight uses:

```text
3 × VL53L0X
```

These sensors provide short-range distance information during parking and other close-range manoeuvres.

All three devices share the I2C bus.

VL53L0X sensors begin with the same default I2C address, so they cannot simply be enabled simultaneously without address management.

The current system therefore uses three XSHUT control lines:

```text
GPIO16
GPIO20
GPIO21
```

Conceptually:

```text
ALL SENSORS OFF
      ↓
ENABLE SENSOR 1
      ↓
ASSIGN WORKING ADDRESS
      ↓
ENABLE SENSOR 2
      ↓
ASSIGN WORKING ADDRESS
      ↓
ENABLE SENSOR 3
      ↓
ASSIGN WORKING ADDRESS
      ↓
NORMAL DISTANCE READING
```

The current three-sensor interface is:

```text
src/TOF_22.py
```

The low-level test program is:

```text
src/TUF_test.py
```

Before running parking logic, verify that:

```text
Sensor 1 responds
Sensor 2 responds
Sensor 3 responds
Distances are plausible
Sensor identities remain separate
```

---

# 10. Camera Architecture

Starlight uses:

```text
2 × Raspberry Pi Camera Module 3 Wide
```

The cameras provide visual information for:

- wall detection;
- pillar detection;
- course-marker detection;
- parking geometry;
- terminal positioning.

The current Starlight camera architecture uses a fixed mechanical arrangement and task-specific image regions.

Both cameras should be visible to Raspberry Pi OS.

Verify using:

```bash
rpicam-hello --list-cameras
```

Both expected cameras should appear.

A camera being detected by Linux does not prove that it has the correct:

- position;
- orientation;
- camera index;
- field of view;
- calibration;
- image exposure.

These must also be checked on the physical robot.

---

# 11. Current Vision Geometry

The current multi-ROI architecture uses a:

```text
720 × 360
```

vision coordinate system.

Different regions of the frame are assigned different purposes.

Conceptually:

```text
┌───────────────────────────────────────────┐
│ L1      L2        C        R2       R1    │
│                                           │
│            COURSE COLOUR ROI              │
│                                           │
│              BODY EXCLUSION               │
└───────────────────────────────────────────┘
```

Typical region responsibilities include:

```text
L1 / R1
→ outer-wall geometry

L2 / R2
→ inner-wall geometry

C
→ center reference

O / B
→ orange / blue course information

BODY
→ excluded robot structure
```

The robot's own body can appear as a dark object.

Pixels corresponding to visible robot structure are therefore excluded from relevant wall-processing regions.

---

# 12. Current Vision Module

The final multi-ROI perception module is:

```text
src/N_Vision_final.py
```

The processing system uses combinations of:

- HSV information;
- LAB information;
- darkness thresholds;
- image location;
- contour area;
- contour geometry;
- region identity.

Conceptual pipeline:

```text
CAMERA FRAME
      ↓
COLOUR-SPACE CONVERSION
      ↓
ROI SELECTION
      ↓
MASK / THRESHOLD
      ↓
MORPHOLOGICAL FILTERING
      ↓
CONTOUR EXTRACTION
      ↓
AREA / GEOMETRY CHECK
      ↓
REGION-AWARE TARGET
      ↓
CONTROLLER
```

Vision should never be assumed to remain calibrated after a major change in:

- lighting;
- camera position;
- camera angle;
- exposure;
- chassis geometry;
- competition field material.

---

# 13. Field Calibration

The current calibration utility is:

```text
src/Cal_APOC.py
```

It supports interactive adjustment of the colour-processing ranges used by the final vision system.

Calibration should be performed using the actual field environment whenever practical.

The calibration workflow should verify:

```text
RED
GREEN
BLACK
BLUE
ORANGE
MAGENTA
```

before a final competition run.

A threshold that worked in the workshop should not automatically be assumed correct under different lighting.

---

# 14. MPU6050 Heading

Heading support is implemented in:

```text
src/heading.py
```

The MPU6050 communicates over I2C.

Enable I2C using:

```bash
sudo raspi-config
```

Then:

```text
Interface Options
→ I2C
→ Enable
```

Verify connected I2C devices:

```bash
i2cdetect -y 1
```

The heading sensor is normally expected at:

```text
0x68
```

The heading process conceptually performs:

```text
INITIALIZE
    ↓
MEASURE STATIONARY BIAS
    ↓
READ ANGULAR VELOCITY
    ↓
REMOVE BIAS
    ↓
INTEGRATE OVER TIME
    ↓
RELATIVE HEADING
```

Keep Starlight stationary during initial gyro calibration.

The heading estimate is a local relative reference.

It is not a drift-free global compass.

---

# 15. Motor Encoder

The current drive motor includes a quadrature encoder.

The encoder provides:

```text
shaft rotation
+
direction information
```

Encoder feedback is used during:

- drivetrain testing;
- movement verification;
- selected controlled movements;
- encoder-assisted challenge manoeuvres.

The dedicated test program is:

```text
src/encoder_test.py
```

Before relying on encoder movement:

```text
1. Rotate the drivetrain.
2. Confirm that counts change.
3. Confirm the expected direction sign.
4. Verify forward movement.
5. Verify reverse movement.
6. Check for stalled or inconsistent encoder response.
```

Encoder movement does not guarantee identical physical ground travel.

Wheel slip and drivetrain play remain possible.

---

# 16. Steering Test

The dedicated steering test is:

```text
src/servo_test.py
```

It should be used to verify:

```text
LEFT
CENTER
RIGHT
```

and to confirm:

- correct steering direction;
- center calibration;
- safe steering limits;
- linkage clearance;
- absence of binding.

Excessive steering travel can damage or disconnect the steering mechanism.

The physically tested steering calibration should therefore be treated as authoritative.

---

# 17. Parking Architecture

The current parking controller is:

```text
src/parking_final.py
```

Parking combines:

```text
CAMERA GEOMETRY
+
MPU6050 HEADING
+
3 × VL53L0X
+
DRIVE CONTROL
+
ACKERMANN STEERING
```

The terminal objective is to stop with Starlight aligned parallel to the magenta parking wall.

Because Starlight uses Ackermann steering, the vehicle cannot rotate about its center.

Parking therefore uses controlled:

```text
FORWARD ARCS
+
REVERSE ARCS
```

rather than differential-drive rotation.

---

# 18. Parking Distance Logic

The current parking design uses repeated short-range measurements rather than relying exclusively on fixed timing or camera position.

Conceptually:

```text
ENTER PARKING STATE
       ↓
ALLOW SENSOR ACTIVATION
       ↓
READ DISTANCE
       ↓
QUALIFY DETECTION
       ↓
WAIT / COOLDOWN
       ↓
CONFIRM SECOND DETECTION
       ↓
CONTINUE PARKING MANOEUVRE
       ↓
RANGE-BASED STOP
```

This reduces the chance that one transient short-distance reading immediately terminates a movement.

The actual thresholds, delays and sensor identities must come from the physically tested source.

---

# 19. Clockwise and Anticlockwise Parking

The final architecture supports both course directions.

Conceptually:

```text
               COURSE COMPLETE
                      │
              DETERMINE DIRECTION
                 ┌─────┴─────┐
                 │           │
                CW          ACW
                 │           │
           CW POSITION     U-TURN
                 │           │
                 │      FOLLOW WALL
                 │           │
                 │     OPPOSITE CORNER
                 └─────┬─────┘
                      │
             SHARED FINAL PARKING
                      │
              PARALLEL FINAL STOP
```

The anticlockwise route changes how Starlight reaches the parking entry.

The final parking routine is shared once the appropriate entry condition is reached.

---

# 20. Dependency Verification

After installation, verify the main software dependencies:

```bash
python3 - <<'PY'
import cv2
import numpy
import smbus2
import RPi.GPIO as GPIO
from picamera2 import Picamera2

print("OpenCV:", cv2.__version__)
print("NumPy:", numpy.__version__)
print("SMBus2: OK")
print("GPIO: OK")
print("Picamera2: OK")
print("Team Sentio dependency check: PASS")
PY
```

The VL53L0X dependency should be verified against the imports used by the committed `TOF_22.py` and `TUF_test.py`. Do not substitute a different library merely because it supports the same sensor model.

---

# 21. Verify Local Team Sentio Modules

After the final source files are uploaded, run module-import checks from the repository root.

At minimum, confirm that the current competition modules can be imported without a missing local dependency.

The expected source set includes:

```text
Cal_APOC.py
Final_Obstacle_Challenge.py
N_Vision_final.py
Sentio_Open_2026.py
openvision.py
TOF_22.py
TUF_test.py
drive.py
encoder_test.py
heading.py
parking_final.py
servo_test.py
```

All local modules imported by these files must also be present and synchronized with the physically tested Raspberry Pi source.

If Python reports:

```text
ModuleNotFoundError
```

for a Team Sentio module, the repository is not yet reproducible.

---

# 22. Component-Test Sequence

Before executing a complete challenge controller, test the individual subsystems.

Recommended order:

```text
STEERING TEST
      ↓
MOTOR TEST
      ↓
ENCODER TEST
      ↓
CAMERA TEST
      ↓
VISION TEST
      ↓
MPU6050 TEST
      ↓
ToF TEST
      ↓
LOW-SPEED INTEGRATION
      ↓
OPEN / OBSTACLE TEST
      ↓
PARKING TEST
```

Relevant utilities:

```text
servo_test.py
encoder_test.py
TUF_test.py
Cal_APOC.py
heading.py
```

Testing individual components first makes faults easier to isolate.

---

# 23. Clean-Clone Reproduction

Clone the repository using:

```bash
git clone https://github.com/teamsentiorobotics-svg/World-Robot-Olympiad---Team-Sentio-.git
cd World-Robot-Olympiad---Team-Sentio-
```

Then verify the expected structure.

```text
.
├── README.md
├── CHANGELOG.md
├── requirements.md
├── .gitattributes
├── .gitignore
│
├── src/
├── docs/
├── Models/
├── schemes/
├── v-photos/
├── t-photos/
├── videos/
└── other/
```

The exact folder capitalization used by the final GitHub repository should remain consistent across documentation and links.

---

# 24. Reproduction Sequence

Recommended full software reproduction sequence:

```text
INSTALL RASPBERRY PI OS
        ↓
UPDATE SYSTEM
        ↓
INSTALL REQUIRED PACKAGES
        ↓
ENABLE I2C
        ↓
CLONE REPOSITORY
        ↓
VERIFY CAMERAS
        ↓
VERIFY MPU6050
        ↓
VERIFY 3 × VL53L0X
        ↓
VERIFY STEERING
        ↓
VERIFY MOTOR
        ↓
VERIFY ENCODER
        ↓
CALIBRATE VISION
        ↓
RUN LOW-SPEED TEST
        ↓
RUN OPEN CHALLENGE
        ↓
RUN OBSTACLE CHALLENGE
        ↓
VERIFY PARKING
```

Do not begin with a full-speed autonomous run on an unverified installation.

---

# 25. Physical Pre-Run Check

Before a complete competition run, verify:

```text
Battery secure
Battery charged
Correct polarity
Regulated Pi supply stable
Common electrical reference present
No exposed short-risk wiring
Motor mechanically free
Gears correctly engaged
Differential mechanically free
Steering linkage connected
Steering center correct
Steering limits safe
Encoder operational
Camera 1 operational
Camera 2 operational
Vision calibrated
MPU6050 operational
ToF 1 operational
ToF 2 operational
ToF 3 operational
Correct source revision loaded
```

A software test should not be used to compensate for an obvious mechanical or electrical fault.

---

# 26. Current Hardware / Software Relationship

The current Starlight architecture can be summarized as:

```text
2 × CAMERA MODULE 3 WIDE
            ↓
     MULTI-ROI VISION
            ↓
  WALL / PILLAR / COLOUR DATA
            │
            │
MPU6050 ────┤
            │
ENCODER ────┤
            │
3 × ToF ────┤
            ↓
     RASPBERRY PI 5
            ↓
     NAVIGATION STATE
            ↓
       DRIVE CONTROL
        ┌────┴────┐
        │         │
      MOTOR     SERVO
        │         │
        └────┬────┘
            ↓
     4WD + ACKERMANN
```

This architecture should remain consistent across:

```text
Engineering Journal
GitHub source
Wiring documentation
CAD
Physical robot
```

---

# 27. Requirements Versioning Policy

Dependencies and configuration values should not be invented retrospectively.

If an exact package version was not recorded from the physically tested Raspberry Pi environment, do not claim that an arbitrary version was used.

The final frozen release should ideally record:

```text
Python version
OpenCV version
NumPy version
Picamera2 version
GPIO implementation
SMBus implementation
VL53L0X library
Raspberry Pi OS version
```

using values obtained directly from the competition Raspberry Pi.

---

# 28. Record the Raspberry Pi Environment

Useful commands include:

```bash
python3 --version
```

```bash
python3 -c "import cv2; print(cv2.__version__)"
```

```bash
python3 -c "import numpy; print(numpy.__version__)"
```

```bash
uname -a
```

```bash
cat /etc/os-release
```

Package information can also be retained using:

```bash
python3 -m pip freeze
```

or:

```bash
dpkg -l
```

Do not blindly replace manually documented dependencies with the entire package list.

The final requirements should distinguish software required by Starlight from unrelated packages installed on the Raspberry Pi.

---

# 29. Record the Exact Git Revision

The exact source revision running on Starlight can be obtained using:

```bash
git rev-parse HEAD
```

Check for local modifications:

```bash
git status
```

A final competition Raspberry Pi should not contain undocumented code changes that are absent from GitHub.

The desired relationship is:

```text
PHYSICAL ROBOT
      =
RASPBERRY PI SOURCE
      =
GITHUB SOURCE
      =
DOCUMENTATION
```

---

# 30. Calibration Changes

Any change to the following may alter autonomous behaviour:

```text
steering center
steering limits
motor speed
proportional gain
camera position
camera angle
ROI position
HSV thresholds
LAB thresholds
pillar area threshold
wall target
marker logic
heading target
encoder target
ToF threshold
parking confirmation timing
```

After modifying one of these values, the robot should be physically tested again before that source revision is identified as a final competition release.

---

# 31. Reproducibility Requirement

The GitHub repository must not rely on:

```text
an undocumented Python module
an uncommitted calibration file
a hidden Raspberry Pi script
a locally edited dependency
an unrecorded CAD component
an unknown wiring change
```

that exists only on the original Starlight robot.

Everything required to reproduce the submitted configuration should be present in or clearly referenced by the repository.

---

# 32. Related Project Files

| Resource | Location |
|---|---|
| Main project overview | `README.md` |
| Development history | `CHANGELOG.md` |
| Engineering Journal | `ENGINEERING_JOURNAL.pdf` |
| Raspberry Pi setup | `docs/pi_setup_instruction.md` |
| Software dependencies | `docs/Software_Dependencies.md` |
| Bill of materials | `docs/BOM_purchase_links.md` |
| Wiring guide | `docs/wiring_guide.md` |
| Differential background | `docs/differential_drive_system.md` |
| Final multi-ROI vision | `src/N_Vision_final.py` |
| Open Challenge | `src/Sentio_Open_2026.py` |
| Open vision | `src/openvision.py` |
| Drive / steering / encoder interface | `src/drive.py` |
| Three-ToF interface | `src/TOF_22.py` |
| Obstacle Challenge | `src/Final_Obstacle_Challenge.py` |
| Parking | `src/parking_final.py` |
| Heading | `src/heading.py` |
| Colour calibration | `src/Cal_APOC.py` |
| Steering test | `src/servo_test.py` |
| Encoder test | `src/encoder_test.py` |
| ToF test | `src/TUF_test.py` |
| Electrical documentation | `schemes/` |
| CAD / printable models | `Models/` |
| Vehicle photographs | `v-photos/` |
| Team photographs | `t-photos/` |
| Autonomous video evidence | `videos/` |

---

# 33. Final Software Freeze Checklist

Before identifying the GitHub repository as the final competition release:

```text
[ ] Final Open controller uploaded
[ ] Final Obstacle controller uploaded
[ ] Final parking controller uploaded
[ ] Final drive-control module (`drive.py`) uploaded
[ ] Final three-ToF interface (`TOF_22.py`) uploaded
[ ] Final multi-ROI vision uploaded
[ ] Open vision uploaded
[ ] heading.py uploaded
[ ] Cal_APOC.py uploaded
[ ] servo_test.py uploaded
[ ] encoder_test.py uploaded
[ ] TUF_test.py uploaded

[ ] All local imports resolve

[ ] Both cameras work
[ ] MPU6050 works
[ ] Encoder works
[ ] ToF 1 works
[ ] ToF 2 works
[ ] ToF 3 works
[ ] Steering works
[ ] Drive motor works

[ ] Vision calibration verified
[ ] Open Challenge tested
[ ] Obstacle Challenge tested
[ ] Parking tested

[ ] Raspberry Pi has no undocumented local changes
[ ] GitHub matches Raspberry Pi
[ ] Documentation matches GitHub
[ ] Engineering Journal matches final configuration
```

---

# Final Software Principle

A reproducible robotics project requires more than the primary challenge program.

The final Starlight release must preserve:

```text
SOURCE CODE
     +
DEPENDENCIES
     +
CALIBRATION
     +
HARDWARE INTERFACES
     +
TEST PROGRAMS
     +
CAD
     +
WIRING
     +
DOCUMENTATION
```

The repository should therefore allow another technically competent person to understand how Starlight is built, how its software is installed, how each subsystem is verified and which exact configuration produced the documented competition behaviour.

---

**Team Sentio**  
**Starlight**  
**World Robot Olympiad — Future Engineers 2026**  
**Robofun Lab (RFL), India**

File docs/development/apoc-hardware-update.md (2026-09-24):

# APOC Hardware Update

**Project:** Starlight  
**Team:** Sentio 6010  
**Competition:** WRO Future Engineers 2026  
**Update:** Post-Nationals → Asia Pacific Open Championship (APOC)  
**Hardware Configuration:** Revision 29  
**Update Date:** September 2026

---

## Overview

Following the WRO India National Championship, Team Sentio did not simply retune the existing Starlight configuration.

The Nationals runs exposed limitations in:

- camera field geometry;
- obstacle clearance;
- parking information;
- drivetrain operating margin;
- movement repeatability;
- sensor placement;
- mechanical packaging.

The robot was therefore redesigned as a **complete integrated system** before APOC.

The post-Nationals development cycle was:

```text
Nationals configuration
        ↓
Competition observations
        ↓
Identify mechanical and sensing limitations
        ↓
Redesign chassis and mounts
        ↓
Reposition cameras
        ↓
Add distance sensing
        ↓
Change drivetrain operating point
        ↓
Add encoder feedback
        ↓
Update perception and parking architecture
        ↓
Component testing
        ↓
Integrated APOC configuration
```

The result is the current **APOC-oriented Starlight architecture**.

---

# Major Hardware Changes

| Subsystem | Nationals / Earlier Approach | APOC Configuration | Reason for Change |
| --- | --- | --- | --- |
| **Chassis** | Earlier competition chassis | Redesigned chassis and mounting structure | Support revised camera, sensor and drivetrain geometry |
| **Camera position** | Earlier mounting arrangement | Rear-mounted / rearward camera arrangement | Improve useful field geometry |
| **Camera mounts** | Earlier printed/support structures | Redesigned rigid mounts | Make camera pose more repeatable |
| **Vision geometry** | Earlier broad viewing arrangement | Camera geometry designed around task-specific ROIs | Reduce irrelevant visual information |
| **Distance sensing** | Camera and heading relied on more heavily | **3 × VL53L0X ToF sensors** | Directly measure nearby physical gaps |
| **Drive motor** | Earlier higher-speed drivetrain configuration | **12 V, 600 RPM geared encoder motor** | Improve usable torque and operating margin |
| **External gearing** | Earlier speed-increasing transmission | **1:1 gearing** | Prioritize torque and controllability |
| **Drive feedback** | Primarily time-based movement | **Quadrature encoder feedback** | Improve movement repeatability |
| **Parking sensing** | Camera + heading | Camera + heading + ToF + movement feedback | Measure both orientation and clearance |
| **Sensor mounts** | Added around earlier packaging | Mounting redesigned around sensing direction | Ensure sensors observe the intended physical surfaces |

---

# Development Background

Starlight has passed through several major physical configurations.

```text
Fully LEGO prototype
        ↓
Hybrid LEGO + printed structure
        ↓
Nationals configuration
        ↓
Post-Nationals redesign
        ↓
Current APOC configuration
```

Photographs of the earlier **fully LEGO**, **hybrid LEGO + 3D-printed**, and later robot configurations are retained in:

```text
v-photos/
```

These images are included as development evidence rather than being presented as photographs of the current competition robot.

The development history matters because the final design was reached through repeated physical iteration, not through a single finished CAD model.

---

# Why the Robot Was Redesigned After Nationals

Nationals produced useful whole-system evidence.

The earlier robot demonstrated that it could complete the Open Challenge, but the Obstacle Challenge also exposed physical interaction and parking limitations.

A correct visual detection does not automatically produce a safe vehicle path.

The complete chain is:

```text
Camera observes feature
        ↓
Software classifies feature
        ↓
Controller selects action
        ↓
Steering mechanism changes wheel direction
        ↓
Drivetrain moves vehicle
        ↓
Physical clearance determines success
```

A failure anywhere in this chain can appear as a navigation failure.

For APOC, several problems were therefore addressed through **hardware architecture changes**, not merely software tuning.

---

# 1. Chassis Redesign

The post-Nationals chassis was redesigned to support the revised sensing architecture.

The objective was not simply to make Starlight look different.

The chassis determines:

- camera location;
- camera height;
- camera angle;
- sensor direction;
- electronics position;
- drivetrain alignment;
- wire routing;
- wheel clearance;
- steering clearance;
- maintenance access.

The APOC redesign therefore treated the chassis as part of the sensing and control system.

```text
Required observation
        ↓
Required sensor position
        ↓
Required mount geometry
        ↓
Required chassis geometry
```

---

## Mechanical Design Principle

Starlight uses a hybrid construction philosophy:

```text
3D-printed structure
        +
LEGO Technic mechanisms
```

Printed components are used where **repeatable geometry** is important.

LEGO Technic components are retained where:

- adjustment;
- rapid repair;
- shaft alignment;
- steering modification;
- gear servicing

are useful.

This allows the robot to combine rigid reference geometry with serviceable mechanisms.

---

# 2. Camera Relocation

One of the largest APOC changes was the camera arrangement.

The earlier physical configuration restricted the useful field of view.

For the APOC design, the camera mounts were relocated toward the **rear of the robot**, allowing the cameras to look forward over more of the useful working area.

The current arrangement uses:

```text
2 × Raspberry Pi Camera Module 3 Wide
```

with rigid camera supports.

---

## Why Camera Position Is a Hardware Decision

A perception problem is not always a software problem.

Moving a camera changes:

- where walls appear in the image;
- where pillar bases appear;
- how early an obstacle becomes visible;
- perspective distortion;
- how much of the robot enters the frame;
- which pixels should belong to each ROI.

Therefore:

```text
Camera position
      ↓
Image geometry
      ↓
ROI placement
      ↓
Detection
      ↓
Steering decision
```

Threshold tuning alone cannot compensate for unsuitable physical camera geometry.

---

# 3. Camera Angle

The current camera arrangement uses a viewing direction of approximately:

```text
60° from horizontal
```

The purpose is to emphasize the nearby track region where immediate navigation information appears.

This improves observation of:

- floor geometry;
- wall boundaries;
- pillar bases;
- coloured course markers;
- parking references.

The trade-off is:

- reduced long-distance look-ahead;
- greater perspective change as objects approach;
- increased importance of rigid mounting.

For this reason, camera angle is treated as a **controlled mechanical parameter**.

---

# 4. Redesigned Camera Mounts

The camera mounts were redesigned together with the chassis.

A camera mount must do more than physically hold a camera.

It must preserve:

```text
Position
+
Angle
+
Orientation
+
Rigidity
```

because small movements can shift the apparent pixel location of a wall or obstacle.

The mount therefore forms part of the perception system.

---

# 5. Robot-Body Visibility

The revised rearward camera position can allow parts of Starlight itself to enter the camera frame.

Instead of moving the cameras back to a worse viewing position, the design accepts the useful camera geometry and removes the known robot-body area in software.

```text
Camera position optimized
        ↓
Robot body partly visible
        ↓
Known body region excluded
        ↓
Remaining image used for navigation
```

This allows physical camera placement to be selected for useful field geometry rather than merely for producing an unobstructed photograph.

---

# 6. Three VL53L0X Distance Sensors

The APOC robot adds:

```text
3 × VL53L0X
Time-of-Flight distance sensors
```

These sensors provide local physical distance information.

They are particularly useful during:

- parking;
- wall-relative positioning;
- final stopping;
- close-range manoeuvres.

---

## Why Distance Sensors Were Added

A camera can answer:

```text
What feature can I see?
```

The IMU can answer:

```text
How much have I turned?
```

The encoder can answer:

```text
How much has the motor shaft moved?
```

The ToF sensors answer a different question:

```text
How far away is the nearby physical surface?
```

These measurements are complementary.

---

# 7. Three Sensors on One I2C Bus

All three VL53L0X sensors initially use the same default I2C address.

To operate three identical sensors on the same bus, Starlight uses separate **XSHUT** lines.

The current hardware allocation is:

| Sensor Control | GPIO |
| --- | ---: |
| **ToF XSHUT 1** | GPIO16 |
| **ToF XSHUT 2** | GPIO20 |
| **ToF XSHUT 3** | GPIO21 |

Initialization follows the general sequence:

```text
Disable all sensors
        ↓
Enable sensor 1
        ↓
Assign unique address
        ↓
Enable sensor 2
        ↓
Assign unique address
        ↓
Enable sensor 3
        ↓
Assign unique address
        ↓
Read all sensors independently
```

The dedicated hardware test is:

```text
src/TUF_test.py
```

---

# 8. Distance-Sensor Mounting

Adding three sensors is useful only if each sensor observes the intended surface.

Mounting direction therefore became part of the hardware redesign.

A valid reading from a poorly positioned sensor may still describe the **wrong object**.

Therefore each sensor must be checked for:

- orientation;
- field of view;
- expected surface;
- minimum useful range;
- interference from robot structure;
- consistency during the relevant parking phase.

The physical mount and software state must agree on what the measurement represents.

---

# 9. New Drive Motor

The drivetrain was revised around a:

```text
12 V
600 RPM
geared DC motor
with integrated quadrature encoder
```

The earlier drivetrain experienced high-load stall behaviour.

That failure demonstrated that maximum speed was not the only important design requirement.

---

## Previous Failure Chain

```text
High mechanical load
        ↓
Motor stall
        ↓
High current stress
        ↓
Motor-driver damage
        ↓
Drivetrain redesign
```

For APOC, the drivetrain operating point was changed to favour:

- available torque;
- reliability;
- controllability;
- movement feedback.

---

# 10. 1:1 External Gearing

The current external gear ratio is:

```text
1 : 1
```

An earlier configuration used a speed-increasing transmission.

The 1:1 arrangement reduces the emphasis on maximum theoretical wheel speed and preserves more available wheel torque.

```text
Earlier design
Speed increase
      ↓
Higher theoretical speed
      ↓
Lower torque margin

Current design
1:1 gearing
      ↓
More torque margin
      ↓
More controllable movement
```

The APOC drivetrain therefore treats reliable completion as more important than theoretical maximum velocity.

---

# 11. Encoder Feedback

The new motor includes a quadrature encoder.

The encoder provides information about:

```text
shaft rotation
+
rotation direction
```

This makes it possible to perform motion requests based on measured drivetrain movement instead of relying entirely on timing.

---

## Time-Based Motion

```text
Drive for X seconds
```

can change with:

- battery voltage;
- motor loading;
- grip;
- drivetrain friction;
- starting velocity.

---

## Encoder-Assisted Motion

```text
Set movement target
        ↓
Read encoder
        ↓
Drive
        ↓
Compare current count with target
        ↓
Stop when target is reached
```

Encoder feedback improves repeatability, although wheel slip can still make actual vehicle travel differ from calculated shaft travel.

---

# 12. Updated Drivetrain Operating Point

The current drivetrain uses:

| Parameter | APOC Configuration |
| --- | --- |
| Motor | 12 V, 600 RPM geared DC encoder motor |
| External ratio | 1:1 |
| Drive architecture | 4WD |
| Steering | Front Ackermann |
| Differential | Mechanical |
| Motion feedback | Quadrature encoder |
| Wheel diameter | 46 mm |

This configuration is documented separately in:

```text
docs/hardware/drivetrain.md
```

---

# 13. Parking Hardware Architecture

Parking was one of the major reasons for expanding the sensing system.

The current parking hardware combines:

```text
Camera
+
MPU6050
+
3 × VL53L0X
+
Encoder
+
Ackermann steering
```

Each component supplies different information.

| Hardware | Parking Information |
| --- | --- |
| Camera | Course and parking geometry |
| MPU6050 | Relative orientation / heading |
| ToF sensors | Nearby physical distance |
| Encoder | Shaft-motion feedback |
| Steering servo | Vehicle curvature |
| Drive motor | Forward / reverse movement |

---

# 14. Why Parking Required Hardware Changes

The earlier approach relied more heavily on camera interpretation, heading and timed movement.

However:

```text
Correct heading
≠
Correct wall clearance
```

and:

```text
Correct distance
≠
Correct orientation
```

The APOC architecture therefore measures both.

```text
Visual geometry
      +
Heading
      +
Physical distance
      +
Movement
      ↓
Parking decision
```

---

# 15. Ackermann Parking Constraint

Starlight uses front Ackermann steering.

This means it cannot rotate in place like a differential-drive robot.

Parking must therefore use:

```text
Forward arc
     +
Reverse arc
     +
Alignment correction
```

The post-Nationals sensor additions were designed around this physical constraint rather than assuming that software alone could eliminate it.

---

# 16. Sensor Architecture After APOC Redesign

The current robot uses four different sensing principles.

| Sensor | What It Measures |
| --- | --- |
| **Camera Module 3 Wide ×2** | Appearance and image geometry |
| **MPU6050** | Angular-rate / relative heading information |
| **VL53L0X ×3** | Nearby physical distance |
| **Quadrature encoder** | Motor-shaft movement and direction |

The design deliberately avoids asking one sensor to solve every problem.

```text
Camera → What is visible?
IMU    → How much did we turn?
Encoder → How much did the shaft move?
ToF    → How large is the nearby gap?
```

---

# 17. Updated Hardware Inventory

The principal APOC hardware includes:

| Qty. | Component | Role |
| ---: | --- | --- |
| 1 | Raspberry Pi 5, 4 GB | Main computer |
| 2 | Raspberry Pi Camera Module 3 Wide | Vision |
| 3 | VL53L0X ToF sensors | Short-range distance |
| 1 | MPU6050-based module | Heading feedback |
| 1 | 12 V, 600 RPM geared encoder motor | Propulsion |
| 1 | Integrated quadrature encoder | Motion feedback |
| 1 | TB6612FNG | Motor drive |
| 1 | DS3225 servo | Ackermann steering |
| 1 | 3S battery system | Main vehicle power |
| Multiple | PLA printed structures | Rigid mounting and packaging |
| Multiple | LEGO Technic elements | Drivetrain and adjustable mechanisms |

---

# 18. Wiring Additions

The APOC changes introduced additional wiring requirements.

Important interfaces include:

| Function | Interface |
| --- | --- |
| Motor direction | GPIO5 / GPIO6 |
| Motor PWM | GPIO13 |
| Steering servo | GPIO22 |
| I2C SDA | GPIO2 |
| I2C SCL | GPIO3 |
| MPU6050 | I2C, address `0x68` |
| ToF XSHUT 1 | GPIO16 |
| ToF XSHUT 2 | GPIO20 |
| ToF XSHUT 3 | GPIO21 |
| Encoder | C1 / C2 from integrated motor encoder |

The complete wiring reference is maintained separately in:

```text
docs/hardware/wiring-guide.md
```

---

# 19. Mechanical Mount Changes

The post-Nationals redesign required new printed components for:

- camera mounting;
- rear sensor / camera structure;
- electronics support;
- ToF positioning;
- revised chassis packaging.

The purpose of these parts was not cosmetic.

They establish controlled geometry between:

```text
Robot
Sensor
Track
```

For perception hardware, mount design is therefore part of sensor calibration.

---

# 20. CAD and Printed Parts

Current and historical CAD evidence is maintained in:

```text
Models/
```

and vehicle photographs are maintained in:

```text
v-photos/
```

The repository should distinguish clearly between:

```text
Historical prototype
Earlier Nationals configuration
Current APOC configuration
```

so that an older CAD render is not accidentally interpreted as the final robot.

---

# 21. Hardware Change → Software Consequence

Although this document focuses on hardware, the APOC redesign directly changed the software requirements.

| Hardware Change | Software Consequence |
| --- | --- |
| Camera relocation | New image geometry |
| Fixed camera pose | Stable ROI positions |
| Rearward mounting | Body-exclusion requirement |
| Three ToF sensors | Multi-sensor initialization and parking states |
| Encoder motor | Encoder-assisted movement |
| 1:1 gearing | Movement values retuned |
| New chassis | Obstacle and parking paths retuned |
| Revised sensor placement | New stopping and confirmation conditions |

Hardware and software were therefore developed together.

---

# 22. Current Vision Relationship

The revised camera hardware enabled the final multi-ROI vision architecture.

The principal final vision file is:

```text
src/N_Vision_final.py
```

The frame is divided into regions with different jobs rather than treating every detected colour anywhere in the image as equivalent.

Typical information includes:

- inner wall;
- outer wall;
- centre reference;
- pillar region;
- course marker;
- parking cue.

This architecture depends on the camera mounts remaining in their calibrated physical position.

---

# 23. Current Parking Relationship

The post-Nationals hardware update also supports:

```text
src/parking_final.py
```

The parking architecture combines:

```text
Vision
      ↓
Heading
      ↓
ToF confirmation
      ↓
Forward / reverse Ackermann motion
      ↓
Final distance condition
```

The hardware redesign and parking software should therefore be treated as one engineering change rather than two unrelated upgrades.

---

# 24. Component-Level Testing

After the redesign, individual hardware functions are tested before a full challenge run.

| Subsystem | Test |
| --- | --- |
| Steering | `src/servo_test.py` |
| Encoder | `src/encoder_test.py` |
| Distance sensing | `src/TUF_test.py` |
| Heading | `src/heading.py` |
| Camera calibration | `src/Cal_APOC.py` |

The intended workflow is:

```text
Mechanical inspection
        ↓
Electrical inspection
        ↓
Individual sensor test
        ↓
Low-speed subsystem test
        ↓
Integrated challenge test
        ↓
Full-speed run
```

---

# 25. APOC Change Summary

The post-Nationals redesign can be summarized as:

```text
NATIONALS
│
├── Earlier chassis
├── Earlier camera geometry
├── Less direct parking-distance information
├── Earlier drivetrain operating point
└── Greater dependence on timing / visual interpretation

                    ↓ REDESIGN ↓

APOC
│
├── Revised chassis
├── Rearward rigid camera arrangement
├── Multi-ROI-compatible camera geometry
├── 3 × VL53L0X distance sensors
├── 600 RPM encoder motor
├── 1:1 external gearing
├── Encoder-assisted movement
├── Revised sensor mounts
└── Camera + IMU + encoder + ToF parking architecture
```

---

# Engineering Rationale

The APOC redesign follows one main principle:

> **A sensor, motor, camera or mount is useful only if its physical placement and behaviour provide information or motion that the controller can use reliably.**

The final robot therefore treats:

```text
Mechanics
+
Electronics
+
Sensing
+
Control
```

as one connected system.

---

# Evidence Status

The following distinctions are intentional:

| Statement | Evidence Type |
| --- | --- |
| Three VL53L0X units are installed | Hardware configuration |
| Motor nominal output is 600 RPM | Component specification |
| External gearing is 1:1 | Current mechanical configuration |
| Encoder reports shaft movement | Sensor function |
| Revised camera placement changes image geometry | Engineering relationship |
| ToF improves access to local gap information | Design rationale |
| Post-Nationals architecture was retained | Development record |

This document does not assign unsupported reliability percentages to the revised hardware.

---

# Related Documentation

| Document | Purpose |
| --- | --- |
| [`../engineering-decisions.md`](../engineering-decisions.md) | Why major design changes were selected |
| [`../failure-log.md`](../failure-log.md) | Failures that drove redesign |
| [`../testing.md`](../testing.md) | Physical verification and test records |
| [`../hardware/drivetrain.md`](../hardware/drivetrain.md) | Current drivetrain architecture |
| [`../hardware/wiring-guide.md`](../hardware/wiring-guide.md) | Electrical connections |
| [`../hardware/bom.md`](../hardware/bom.md) | Current hardware inventory |
| [`../../CHANGELOG.md`](../../CHANGELOG.md) | Chronological project changes |
| [`../../Models/`](../../Models/) | Mechanical design files |
| [`../../v-photos/`](../../v-photos/) | Vehicle and development photographs |
| [`../../src/`](../../src/) | Current robot software |

---

## Final Configuration Rule

Documentation, photographs, code and testing records must clearly distinguish the **current APOC configuration** from older prototypes.

In particular:

```text
Earlier speed-increasing gearing
Earlier motor specifications
Earlier camera locations
Earlier parking architecture
Earlier chassis photographs
```

must not be presented as current hardware.

The current Rev27 hardware configuration is the reference for APOC documentation.

---

**Team Sentio 6010**  
**Starlight**  
**WRO Future Engineers 2026**  
**Robofun Lab (RFL), India**

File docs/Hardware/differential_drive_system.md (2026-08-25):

# Mechanical Differential — Beginner Guide  
### What it is, why a robot needs it, and how to build a Starlight-style drivetrain around it

> **Context:** This guide is written for a beginner building a four-wheel-drive robot with **Ackermann steering**, similar in concept to Team Sentio's **Starlight**.  
> The example drivetrain uses a **36-tooth driving gear → 24-tooth driven gear** stage, giving a **1.5× speed increase** before the wheel-drive system.

---

## 1. What is a mechanical differential?

A **mechanical differential** is a small gearbox that allows the **left and right driven wheels to rotate at different speeds while still receiving power from the same motor**.

That sounds strange at first because we normally want both wheels to move together.

The reason becomes clear when the robot turns.

### When the robot drives straight

Both wheels travel almost the same distance.

```text
LEFT WHEEL   ───────────────►
RIGHT WHEEL  ───────────────►
```

So both wheels can rotate at nearly the same speed.

### When the robot turns

The outside wheel follows a **larger circle** than the inside wheel.

```text
                   OUTSIDE WHEEL
              ┌───────────────────
          ┌───┘
      ROBOT
          └───┐
              └────────
               INSIDE WHEEL
```

The outside wheel therefore has to travel farther in the same amount of time.

That means:

```text
outside wheel speed > inside wheel speed
```

A differential allows this speed difference automatically.

---

# 2. Why is a differential useful?

Imagine connecting the left and right wheels rigidly to one solid axle.

Both wheels would then be forced to rotate at exactly the same speed.

During a turn:

- the outside wheel wants to rotate faster,
- the inside wheel wants to rotate slower,
- but the solid axle forces them to rotate together.

Something has to give.

Usually the tyres begin to:

- scrub,
- slide,
- skip,
- twist the chassis,
- or push the robot away from the intended steering path.

For a small autonomous robot, this can cause:

- inconsistent cornering,
- increased current draw,
- loss of traction,
- larger turning radius,
- unstable camera geometry,
- extra stress on gears and shafts.

A differential solves much of this mechanically.

---

# 3. Why this matters especially with Ackermann steering

Starlight uses **Ackermann-style steering**.

Ackermann steering already tries to make the front wheels point along the correct turning circles.

The inside steering wheel turns more than the outside steering wheel.

But correct wheel angles alone are not enough.

The wheels also need to rotate at the correct **speeds**.

So the two systems solve different parts of the same problem:

| System | What it allows |
|---|---|
| Ackermann steering | Left and right wheels point at different steering angles |
| Differential | Left and right driven wheels rotate at different speeds |

Together they make cornering much smoother.

---

# 4. The simplest way to imagine a differential

Think of the differential as a gearbox with:

```text
                 MOTOR INPUT
                     │
                     ▼
              ┌─────────────┐
              │ DIFFERENTIAL│
              └─────────────┘
                 /         \
                /           \
               ▼             ▼
        LEFT OUTPUT     RIGHT OUTPUT
```

When driving straight:

```text
Left output speed ≈ Right output speed
```

When turning:

```text
Left output speed ≠ Right output speed
```

The motor can continue powering both sides.

---

# 5. What is inside a basic differential?

A normal bevel-gear differential contains four important parts.

## 5.1 Differential housing or carrier

This is the rotating body driven by the motor.

It holds the smaller internal gears.

## 5.2 Ring gear / input gear

The drivetrain rotates the differential housing through this gear.

In LEGO Technic-style builds, the large toothed outer section of the differential often performs this job.

## 5.3 Side gears

There are two side gears:

- one connects to the left axle,
- one connects to the right axle.

## 5.4 Spider gears

Small bevel gears sit between the two side gears.

These are what allow one output axle to rotate faster than the other.

A simplified internal view looks like this:

```text
                     INPUT
                       │
                       ▼
              ┌────────────────┐
              │ rotating case  │
              │                │
 LEFT AXLE ◄──┤ side        side├──► RIGHT AXLE
              │ gear        gear│
              │      ╲  ╱       │
              │      spider     │
              │       gears     │
              └────────────────┘
```

---

# 6. What happens inside the differential?

## Case A — Robot travelling straight

Resistance at both wheels is similar.

The spider gears do not need to rotate much around their own axes.

The entire differential assembly rotates together.

Result:

```text
Left wheel speed ≈ Right wheel speed
```

---

## Case B — Robot turning

The inside wheel experiences a different required speed from the outside wheel.

The spider gears rotate inside the carrier.

This allows:

```text
one output to slow down
while
the other output speeds up
```

The important idea is:

> The differential does not decide which wheel is inside or outside.  
> It simply allows the wheels to rotate at the speeds demanded by the geometry and resistance of the turn.

---

# 7. Basic differential speed rule

For a simple open differential:

\[
\omega_{\text{carrier}}
=
\frac{\omega_L+\omega_R}{2}
\]

where:

- \(\omega_L\) = left-wheel angular speed,
- \(\omega_R\) = right-wheel angular speed,
- \(\omega_{\text{carrier}}\) = differential carrier speed.

### In very simple words

The differential carrier roughly rotates at the **average speed of the two outputs**.

Example:

```text
Left wheel  = 500 rpm
Right wheel = 700 rpm

Average = (500 + 700) / 2
        = 600 rpm
```

The differential can therefore accommodate the difference without forcing both wheels to 600 rpm.

---

# 8. Starlight-style gear stage: 36T → 24T

A drivetrain similar to Starlight can use:

```text
36-tooth driving gear
        ↓
24-tooth driven gear
```

The speed ratio is:

\[
\text{Speed ratio}
=
\frac{36}{24}
=
1.5
\]

So ideally:

```text
output speed = motor-side speed × 1.5
```

Example:

If the input shaft is turning at:

```text
600 rpm
```

then the ideal driven shaft speed is:

```text
600 × 1.5 = 900 rpm
```

### What this means in normal words

The 36T gear is larger than the 24T gear.

One revolution of the larger gear moves more teeth past the contact point, so the smaller gear has to rotate faster.

The trade-off is torque.

Ignoring losses:

\[
\text{Torque multiplier}
=
\frac{24}{36}
=
0.667
\]

So this gearing gives approximately:

```text
1.5× speed
but only about 0.67× torque
```

before friction and drivetrain losses.

That is why gearing must be tested under real robot load rather than chosen only from theoretical speed.

---

# 9. Where should the differential go?

A simple drivetrain layout is:

```text
MOTOR
  │
  ▼
36T GEAR
  │
  ▼
24T GEAR
  │
  ▼
DIFFERENTIAL
 /           \
▼             ▼
LEFT AXLE   RIGHT AXLE
```

For a **4WD robot**, there are several possible layouts.

---

# 10. 4WD differential arrangements

## Option A — One differential on each axle

```text
                    MOTOR
                      │
               central transmission
                 /             \
                ▼               ▼
       FRONT DIFFERENTIAL   REAR DIFFERENTIAL
          /       \            /       \
        FL        FR          RL        RR
```

Where:

- FL = front-left,
- FR = front-right,
- RL = rear-left,
- RR = rear-right.

### Advantages

- mechanically correct for four-wheel drive,
- each axle can accommodate left/right speed differences,
- smoothest turning.

### Disadvantages

- more parts,
- more backlash,
- more alignment work,
- more drivetrain losses.

---

## Option B — One differential with mechanically linked front/rear wheels

A simpler small-robot approach is:

```text
                       DIFFERENTIAL
                      /            \
                LEFT SIDE         RIGHT SIDE
                   │                  │
              shaft / gears       shaft / gears
               /       \           /       \
             FL        RL        FR        RR
```

Each differential output powers one **side** of the robot.

The front and rear wheels on that side are mechanically coupled.

### Advantages

- only one differential,
- compact,
- fewer gears,
- easier to build.

### Limitation

The front and rear wheel on the same side still cannot freely rotate at different speeds.

For a small robot with a short wheelbase and compliant tyres, this may still work well enough.

---

# 11. A practical Starlight-like concept

For a compact Ackermann robot, a useful conceptual drivetrain is:

```text
                        MOTOR
                          │
                          ▼
                     36T GEAR
                          │
                          ▼
                     24T GEAR
                          │
                          ▼
                  DIFFERENTIAL CASE
                    /           \
                   /             \
          LEFT OUTPUT          RIGHT OUTPUT
              │                    │
        left-side drive       right-side drive
          /        \            /        \
        FL          RL        FR          RR
```

This keeps all **four wheels driven** while still allowing the two sides of the robot to rotate at different average speeds.

> The exact shaft routing depends on the chassis.  
> The key design idea is that the differential should be located **before the drivetrain splits into left and right wheel groups**.

---

# 12. Parts needed for a LEGO/Technic-style differential

A beginner-friendly build normally needs:

### Differential components

- 1 differential housing / differential carrier
- 2 side bevel gears
- 2 or more spider bevel gears
- 2 output axles

### Input transmission

- 36T gear
- 24T gear
- motor output shaft
- supporting bearings/bushes

### Wheel transmission

- left output shaft
- right output shaft
- gears or shafts to transmit power to each wheel
- axle bushes / bearings
- wheel hubs

### Structural components

- rigid parallel beams or chassis plates
- cross-bracing
- axle supports
- spacers
- bushes
- retainers

The exact pieces can vary.

The important requirement is **geometry and alignment**, not the colour or exact beam type.

---

# 13. How to build the differential — beginner steps

## Step 1 — Build a rigid frame

Before installing gears, create two parallel structural rails.

```text
SIDE RAIL  =======================

          drivetrain space

SIDE RAIL  =======================
```

The rails should not twist easily.

A flexible frame causes:

- gears to separate,
- shafts to move,
- differential gears to bind.

---

## Step 2 — Install the differential carrier

Place the differential between the frame rails.

Its two output axles should point directly toward the left and right sides.

```text
LEFT SIDE  ◄──── [ DIFFERENTIAL ] ────► RIGHT SIDE
```

The differential must be:

- square to the chassis,
- centred,
- firmly supported.

---

## Step 3 — Support both output axles

Do not allow long unsupported axles.

Bad:

```text
[DIFF]──────────────WHEEL
```

Better:

```text
[DIFF]──[BEARING]──[BEARING]──WHEEL
```

In LEGO construction, a "bearing" is usually a properly aligned beam hole or axle support.

Multiple supports reduce axle bending.

---

## Step 4 — Add the input gear

Mount the gear that drives the differential housing.

Make sure the gears:

- fully mesh,
- are not forced together,
- cannot move sideways.

You should be able to rotate the drivetrain by hand.

---

## Step 5 — Add the 36T → 24T stage

A Starlight-like speed-up stage can be:

```text
motor shaft
    │
   36T
    ⚙
   24T
    │
differential input
```

Check that:

- both shafts are parallel,
- the gears overlap correctly,
- there is almost no sideways movement,
- the teeth do not skip under load.

---

## Step 6 — Connect left and right outputs

Connect:

```text
differential left output → left wheel drivetrain
differential right output → right wheel drivetrain
```

For 4WD, extend each side to both wheels.

Example:

```text
                LEFT OUTPUT
                     │
             ┌───────┴───────┐
             ▼               ▼
         FRONT LEFT       REAR LEFT
```

and similarly for the right side.

---

# 14. Very important: keep the shafts aligned

A differential can work perfectly on a table and still fail inside a robot because of poor shaft alignment.

Look for:

- bent axles,
- beams squeezing gears,
- gears touching structural parts,
- excessive sideways play,
- axle holes that are not parallel.

A good drivetrain should rotate easily by hand.

---

# 15. The hand test

Before connecting the motor, perform this test.

## Test 1 — Rotate the differential input

Both sides should turn smoothly.

## Test 2 — Hold the left wheel

Rotate the differential input.

The right wheel should still be able to rotate.

## Test 3 — Hold the right wheel

The left wheel should still move.

## Test 4 — Rotate one wheel manually

The opposite wheel may rotate in the opposite direction depending on how the drivetrain is constrained.

This is normal differential behaviour.

---

# 16. How to recognise a locked differential

If the left and right outputs are mechanically forced together:

```text
LEFT = RIGHT
```

the drivetrain behaves like a solid axle.

This can improve traction in some conditions, but it removes the main turning advantage of the differential.

For an Ackermann robot, a permanently locked axle usually creates more tyre scrub.

---

# 17. Open differential vs locked differential

| Open differential | Locked differential |
|---|---|
| Left/right speeds may differ | Left/right speeds forced equal |
| Smooth cornering | More tyre scrub |
| Lower mechanical stress in turns | Higher steering resistance |
| Can lose drive if one wheel has almost no traction | Better drive if one wheel slips |
| Good general choice for Ackermann steering | Useful only when traction is more important than turning freedom |

---

# 18. Why not simply control left and right wheels with software?

That is possible if the robot has separate left and right motors.

Software could command:

```text
inside motor  = slower
outside motor = faster
```

But a mechanical differential has an important advantage:

> It solves the speed difference automatically without requiring the computer to calculate exact wheel speeds.

For a robot already using:

- cameras,
- OpenCV,
- obstacle detection,
- heading estimation,
- parking logic,

it can be useful to let mechanics solve a mechanical problem.

---

# 19. Differential and Ackermann geometry together

During a left turn:

```text
Inside = LEFT
Outside = RIGHT
```

The steering geometry produces approximately:

\[
\delta_{\text{inside}} > \delta_{\text{outside}}
\]

and the wheel paths require:

\[
v_{\text{outside}} > v_{\text{inside}}
\]

Ackermann steering helps with the **first relationship**.

The differential helps with the **second relationship**.

That is why they complement each other.

---

# 20. Common beginner mistakes

## Mistake 1 — Building the differential loosely

If the carrier can move sideways, the gears may skip.

### Fix

Brace the differential from both sides.

---

## Mistake 2 — Over-constraining the axles

Too many badly aligned supports can create more friction than too few supports.

### Fix

Use several supports, but make sure they are actually collinear.

---

## Mistake 3 — Gears pressed too tightly together

This increases friction dramatically.

### Fix

Leave tiny mechanical clearance.

The gears should mesh, not grind.

---

## Mistake 4 — Very long unsupported axles

They twist and bend under torque.

### Fix

Place axle supports close to gears and wheels.

---

## Mistake 5 — Ignoring gear backlash

A small amount of gear play is normal.

Too much backlash causes:

- delayed response,
- jerky direction changes,
- inaccurate parking.

### Fix

Shorten the drivetrain and support gears properly.

---

## Mistake 6 — Testing only with the robot lifted

A drivetrain that works with the wheels in the air may fail on the floor.

### Why?

On the floor there is:

- tyre friction,
- robot mass,
- steering load,
- acceleration load.

Always test under real load.

---

# 21. Recommended testing sequence

Use the following order.

```text
1. Differential alone
        ↓
2. Gear train by hand
        ↓
3. Motor at low speed
        ↓
4. Wheels off ground
        ↓
5. Straight driving
        ↓
6. Slow steering
        ↓
7. Full left/right turns
        ↓
8. Higher-speed runs
        ↓
9. Repeated challenge laps
```

Do not go directly from assembly to full motor speed.

---

# 22. Differential troubleshooting

## Problem: drivetrain is difficult to rotate

Possible causes:

- gear mesh too tight,
- shafts misaligned,
- axle rubbing,
- differential squeezed by frame,
- bent axle.

---

## Problem: gears skip under acceleration

Possible causes:

- insufficient shaft support,
- loose frame,
- gear centres moving apart,
- motor torque too high for the structure.

---

## Problem: robot jerks during turning

Possible causes:

- differential binding,
- wheel on one side mechanically locked,
- front/rear coupling too rigid,
- steering geometry incorrect,
- tyre scrub.

---

## Problem: only one wheel spins

This can happen with an open differential when one side has much lower resistance.

Check whether:

- one wheel is lifted,
- one wheel has very low grip,
- the other side is jammed.

---

# 23. Differential design checklist

Before calling the drivetrain complete, check:

- [ ] Differential housing rotates smoothly
- [ ] Left axle rotates freely
- [ ] Right axle rotates freely
- [ ] Holding one side does not lock the entire gearbox
- [ ] 36T and 24T gears remain fully engaged
- [ ] Shafts have support close to major gears
- [ ] No gear rubs against chassis parts
- [ ] Axles cannot slide sideways excessively
- [ ] All four wheels receive drive
- [ ] Robot drives straight without severe binding
- [ ] Full steering lock does not cause excessive tyre hopping
- [ ] Drivetrain survives repeated acceleration and braking

---

# 24. A simple explanation for a judge

If someone asks:

> **Why did you use a mechanical differential?**

A good simple answer is:

> When the robot turns, the outside wheels have to travel farther than the inside wheels, so they cannot rotate at exactly the same speed. A mechanical differential allows the left and right sides of the drivetrain to rotate at different speeds while still receiving power from the same motor. This reduces tyre scrub and drivetrain stress and works well with our Ackermann steering system.

---

# 25. Slightly more technical explanation

> Starlight uses Ackermann steering, which creates different steering angles for the inside and outside wheels. The corresponding wheel paths also have different radii, so the two sides require different rotational speeds. A mechanical differential provides this speed freedom passively. It therefore reduces the need for tyre slip while preserving a single mechanical drive source.

---

# 26. Why the differential is a good engineering solution

The differential is a good example of an important engineering principle:

> **Do not solve every problem in software.**

The computer is already responsible for:

- camera processing,
- colour detection,
- wall geometry,
- state logic,
- obstacle avoidance,
- heading correction,
- parking.

The differential solves a turning-speed problem automatically using gears.

That makes the complete robot easier to control.

---

# 27. Final Starlight-style drivetrain concept

```text
                           MOTOR
                             │
                             ▼
                         [ 36T ]
                             ⚙
                         [ 24T ]
                             │
                             ▼
                    ┌────────────────┐
                    │  DIFFERENTIAL  │
                    └────────────────┘
                       /          \
                      /            \
                     ▼              ▼
               LEFT OUTPUT      RIGHT OUTPUT
                    │                │
             ┌──────┴──────┐  ┌─────┴──────┐
             ▼             ▼  ▼            ▼
        FRONT LEFT     REAR LEFT FRONT RIGHT REAR RIGHT

              ← four driven wheels / 4WD →
```

Combined with Ackermann steering:

```text
CAMERA / CONTROL
       │
       ▼
STEERING SERVO
       │
       ▼
ACKERMANN LINKAGE
       │
       ├── inside wheel: larger steering angle
       └── outside wheel: smaller steering angle

MOTOR
  │
  ▼
DIFFERENTIAL
  │
  ├── inside side: allowed to rotate slower
  └── outside side: allowed to rotate faster
```

This is the key idea:

> **Ackermann controls where the wheels point.  
> The differential allows them to rotate at the speeds the turn requires.**

---

# 28. One-page build summary

### Goal

Build a drivetrain that:

- powers all four wheels,
- allows left/right speed difference,
- works with Ackermann steering.

### Build order

```text
Rigid chassis
   ↓
Differential carrier
   ↓
Left/right output shafts
   ↓
36T → 24T input gearing
   ↓
Motor connection
   ↓
Front/rear side-drive connection
   ↓
Wheel installation
   ↓
Hand test
   ↓
Low-speed powered test
   ↓
Turning test
   ↓
Full robot test
```

### Most important rule

**If the drivetrain does not rotate smoothly by hand, do not fix it by increasing motor power.**

Find the mechanical resistance first.

---

## Final takeaway

A mechanical differential is not just an extra set of gears.

It is a device that allows the drivetrain to match the **geometry of a turn**.

For an Ackermann-steered four-wheel-drive robot, it can make the robot:

- smoother,
- more repeatable,
- easier to steer,
- less mechanically stressed,
- and easier for the software to control.

The best way to understand it is to build one, rotate the outputs by hand, and watch how the gears automatically allow one side to speed up while the other slows down.

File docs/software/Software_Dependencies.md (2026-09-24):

# Software Dependencies

## Team Sentio - WRO Future Engineers 2026

This document records the software environment, external dependencies, module structure, calibration tools, and reproducibility requirements used by **Team Sentio's autonomous vehicle, Starlight** for **World Robot Olympiad 2026 - Future Engineers**.

The dependency record follows the current **Revision 29 competition architecture** documented for the final September 2026 submission.

| Item | Current Configuration |
| --- | --- |
| **Computer** | Raspberry Pi 5, 4 GB |
| **Operating System** | Raspberry Pi OS |
| **Programming Language** | Python 3 |
| **Camera Interface** | Picamera2 |
| **Computer Vision** | OpenCV + NumPy |
| **GPIO Interface** | RPi.GPIO-compatible interface |
| **I2C Interface** | SMBus2 / device-specific sensor interface |
| **Cameras** | 2 × Raspberry Pi Camera Module 3 Wide |
| **Heading Sensor** | MPU6050 |
| **Distance Sensors** | 3 × VL53L0X ToF sensors |
| **Drive Feedback** | Motor encoder |
| **Vision Architecture** | Multi-ROI HSV/LAB processing with body exclusion |
| **Competition Status** | Open, Obstacle and Parking systems physically tested |

> [!IMPORTANT]
> The source running on the physically tested robot is the authoritative competition version.
>
> GitHub, the Raspberry Pi, calibration values, wiring documentation, and engineering journal should remain synchronized whenever the competition configuration changes.

For complete Raspberry Pi installation and wiring information, also see:

- [`pi_setup_instruction.md`](pi_setup_instruction.md)
- [`wiring_guide.md`](wiring_guide.md)
- [`BOM_purchase_links.md`](BOM_purchase_links.md)
- [`testing.md`](testing.md)

---

# Competition Software

The current competition software is stored in the [`src/`](../src/) directory.

The Revision 29 software architecture uses the following principal files:

```text
src/
├── Cal_APOC.py
├── Final_Obstacle_Challenge.py
├── N_Vision_final.py
├── Sentio_Open_2026.py
├── openvision.py
├── TOF_22.py
├── TUF_test.py
├── drive.py
├── encoder_test.py
├── heading.py
├── parking_final.py
└── servo_test.py
```

The current repository therefore includes the competition controllers, vision modules, heading helper, three-ToF interface, low-level drive interface, calibration utility and dedicated component tests required by the documented architecture.

> [!IMPORTANT]
> `openvision.py` is required by the documented Open Challenge architecture and should remain present in `src/` alongside `Sentio_Open_2026.py`.

---

## Module Responsibilities

| File | Responsibility |
| --- | --- |
| [`Cal_APOC.py`](../src/Cal_APOC.py) | Field calibration of LAB and HSV colour thresholds |
| [`Final_Obstacle_Challenge.py`](../src/Final_Obstacle_Challenge.py) | Obstacle selection, course state, movement decisions and transition toward parking |
| [`N_Vision_final.py`](../src/N_Vision_final.py) | Final multi-ROI vision for walls, pillars, markers and parking cues |
| [`Sentio_Open_2026.py`](../src/Sentio_Open_2026.py) | Open Challenge wall following, direction logic and course progress |
| [`openvision.py`](../src/openvision.py) | Primary lightweight Open Challenge vision implementation |
| [`TOF_22.py`](../src/TOF_22.py) | Three-VL53L0X initialization, XSHUT sequencing and distance interface |
| [`TUF_test.py`](../src/TUF_test.py) | VL53L0X distance-sensor communication and ranging tests |
| [`drive.py`](../src/drive.py) | Motor PWM, direction, steering and encoder-assisted movement interface |
| [`encoder_test.py`](../src/encoder_test.py) | Encoder direction, response and movement testing |
| [`heading.py`](../src/heading.py) | MPU6050 calibration and shared relative-heading estimate |
| [`parking_final.py`](../src/parking_final.py) | Direction-dependent parking entry and final parallel-parking behaviour |
| [`servo_test.py`](../src/servo_test.py) | Steering centre, direction and mechanical-travel testing |

The current architecture deliberately separates:

```text
Perception
    ↓
State / decision logic
    ↓
Movement request
    ↓
Drive / steering / encoder interface
    ↓
Changed physical state
    ↓
New sensor observation
```

This makes individual faults easier to isolate than placing every behaviour inside one large script.

---

# Software Architecture

## Open Challenge

The current Open Challenge controller is:

```text
src/Sentio_Open_2026.py
```

The primary vision module is:

```text
src/openvision.py
```

The architecture also allows the final multi-ROI vision module:

```text
src/N_Vision_final.py
```

to be used where its returned observations remain compatible with the controller.

Conceptually:

```text
Sentio_Open_2026.py
│
├── openvision.py
│   ├── OpenCV
│   ├── NumPy
│   └── Picamera2
│
├── optional N_Vision_final.py compatibility
│   ├── OpenCV
│   ├── NumPy
│   └── Picamera2
│
└── drive.py
    ├── GPIO motor control
    ├── steering control
    └── encoder-assisted movement
```

The Open Challenge performs continuous wall correction while separately tracking discrete course events.

A visible course marker may remain in the camera for several frames, so progress detection uses state and cooldown logic rather than counting every frame independently.

---

## Obstacle Challenge

The current Obstacle Challenge controller is:

```text
src/Final_Obstacle_Challenge.py
```

Its high-level architecture is:

```text
Final_Obstacle_Challenge.py
│
├── N_Vision_final.py
│   ├── OpenCV
│   ├── NumPy
│   └── Picamera2
│
├── heading.py
│   └── MPU6050
│
├── parking_final.py
│   ├── camera information
│   ├── heading information
│   ├── TOF_22.py distance information
│   └── movement control
│
└── drive.py
    ├── DC motor
    ├── steering servo
    └── encoder
```

The controller combines:

- red / green pillar observations;
- outer-wall observations;
- inner-wall observations;
- centre-region observations;
- course direction;
- current state;
- heading feedback;
- encoder-assisted movement;
- parking cues;
- short-range distance measurements.

A detected object is therefore **not automatically a movement command**.

Its meaning depends on:

```text
Colour
+
Image region
+
Geometry
+
Course direction
+
Current state
```

---

# External Software Dependencies

The principal external software components are:

| Dependency | Purpose |
| --- | --- |
| **Python 3** | Executes competition and test software |
| **OpenCV (`cv2`)** | Colour processing, masks, morphology, contours and geometry |
| **NumPy** | Image arrays and numerical processing |
| **Picamera2** | Raspberry Pi camera interface |
| **RPi.GPIO-compatible interface** | Motor, steering and digital control |
| **SMBus2** | I2C communication used by the MPU6050 heading module |
| **VL53L0X driver used by final source** | Communication with the three ToF distance sensors |

> [!NOTE]
> The exact VL53L0X Python package must match the imports used by the physically tested `TUF_test.py` and `parking_final.py`.
>
> Do not document or install a different library merely because it supports the same sensor model.

The same rule applies to the encoder interface. The package or GPIO method documented here should match the final tested source rather than an earlier prototype.

---

# Raspberry Pi OS Packages

Install the principal Raspberry Pi OS packages with:

```bash
sudo apt update

sudo apt install -y \
    git \
    python3-picamera2 \
    python3-opencv \
    python3-numpy \
    python3-smbus2 \
    i2c-tools
```

These packages provide:

| Package | Purpose |
| --- | --- |
| `git` | Clone and synchronize the repository |
| `python3-picamera2` | Raspberry Pi camera interface |
| `python3-opencv` | Computer vision |
| `python3-numpy` | Numerical and image-array processing |
| `python3-smbus2` | I2C communication |
| `i2c-tools` | I2C device detection and diagnostics |

Any additional package required by the final ToF or encoder source should be installed according to the imports in that exact tested revision.

---

# Raspberry Pi 5 GPIO Compatibility

The low-level drive software uses an interface compatible with:

```python
import RPi.GPIO as GPIO
```

Test the environment with:

```bash
python3 -c "import RPi.GPIO as GPIO; print('GPIO import OK')"
```

On a Raspberry Pi 5 installation requiring the compatibility implementation:

```bash
sudo apt install -y python3-rpi-lgpio
```

If a conflicting classic implementation is installed:

```bash
sudo apt remove -y python3-rpi.gpio
sudo apt install -y python3-rpi-lgpio
```

Verify again:

```bash
python3 -c "import RPi.GPIO as GPIO; print('GPIO interface OK')"
```

Do not deliberately keep conflicting GPIO implementations that provide the same Python namespace.

---

# I2C Architecture

Starlight uses the Raspberry Pi I2C bus for multiple sensors.

The published baseline is:

```text
SDA: GPIO2
SCL: GPIO3
```

Enable I2C with:

```bash
sudo raspi-config
```

Then select:

```text
Interface Options
→ I2C
→ Enable
```

After rebooting:

```bash
i2cdetect -y 1
```

---

## MPU6050

The MPU6050 heading sensor is expected at:

```text
0x68
```

The shared heading helper is:

```text
src/heading.py
```

It:

1. opens communication with the MPU6050;
2. estimates stationary gyro bias;
3. reads angular rate;
4. compensates for the estimated bias;
5. integrates angular rate over time;
6. returns a relative heading.

Test with:

```bash
python3 src/heading.py
```

Keep Starlight completely stationary during initial calibration.

The heading estimate is a **local relative reference**, not a drift-free global compass.

---

# Three VL53L0X Distance Sensors

Starlight uses:

```text
3 × VL53L0X
```

The sensors share the I2C bus.

Because identical VL53L0X sensors initially use the same default I2C address, they must be enabled individually before assigning separate working addresses.

The current hardware uses three XSHUT lines:

```text
GPIO16
GPIO20
GPIO21
```

Conceptually:

```text
All ToF sensors disabled
        ↓
Enable sensor 1
        ↓
Assign unique address
        ↓
Enable sensor 2
        ↓
Assign unique address
        ↓
Enable sensor 3
        ↓
Assign unique address
        ↓
Read sensors independently
```

The current three-sensor interface is:

```text
src/TOF_22.py
```

The low-level distance test is:

```text
src/TUF_test.py
```

Use it to verify:

- sensor communication;
- sensor identity;
- distance response;
- mounting direction;
- which physical surface each sensor observes.

A distance reading is useful only when the software knows **which sensor produced it and which physical gap it represents**.

---

# Motor Encoder

The current 600 RPM drive motor includes an encoder.

The encoder provides shaft-motion information used for:

- movement testing;
- repeatable movement requests;
- confirming motor response;
- reducing dependence on time-only movement.

The dedicated test is:

```text
src/encoder_test.py
```

Encoder calibration should establish:

```text
Count direction
Counts per shaft rotation
Motor response
Expected movement sign
```

Encoder feedback does **not** guarantee exact vehicle displacement.

Wheel slip, tire deformation and drivetrain compliance can cause body movement to differ from calculated shaft movement.

---

# Drive and Steering Interface

The current low-level drive interface is:

```text
src/drive.py
```

It converts movement requests into:

```text
Motor direction
Motor PWM
Steering command
Encoder-assisted movement
```

Published baseline control connections include:

| Function | Interface |
| --- | --- |
| Motor direction | GPIO5 / GPIO6 |
| Motor PWM | GPIO13 |
| Motor PWM frequency | 1 kHz |
| Steering servo | GPIO22 |
| Steering PWM frequency | 50 Hz |

The exact final steering limits and speed values remain defined by the physically tested source.

Do not duplicate rapidly changing calibration constants in several documentation files.

---

# Camera Dependencies

Starlight uses:

```text
2 × Raspberry Pi Camera Module 3 Wide
```

The two cameras provide different useful views during navigation and parking.

The current camera geometry uses a viewing direction of approximately:

```text
60° from horizontal
```

This emphasizes:

- nearby track surface;
- pillar bases;
- wall geometry;
- course markers;
- parking cues.

The trade-off is reduced distant look-ahead and stronger perspective change as objects approach.

Camera pose is therefore treated as a **mechanical calibration parameter**, not merely a software setting.

---

## Camera Detection Test

List cameras:

```bash
rpicam-hello --list-cameras
```

Test camera 0:

```bash
rpicam-hello --camera 0 --timeout 3000
```

Test camera 1:

```bash
rpicam-hello --camera 1 --timeout 3000
```

Camera numbering, mounting position or orientation should not be changed immediately before competition without rerunning vision and parking tests.

---

# Current Vision Architecture

The final multi-purpose vision module is:

```text
src/N_Vision_final.py
```

The current vision configuration is based on approximately:

```text
Width:  720 px
Height: 360 px
```

The architecture uses multiple task-specific Regions of Interest rather than treating the complete camera frame as one detection region.

Conceptually:

```text
Camera frame
      ↓
Colour-space conversion
      ↓
HSV / LAB processing
      ↓
Task-specific ROIs
      ↓
Morphological filtering
      ↓
Contour extraction
      ↓
Area / shape checks
      ↓
Region-labelled observation
```

---

## Why Multiple ROIs Are Used

Different parts of the image answer different questions.

Typical roles include:

```text
Outer-wall region
Inner-wall region
Centre reference
Orange / blue course-cue region
Pillar regions
Parking-related regions
```

This reduces the chance that an unrelated object elsewhere in the frame is interpreted as the target required by the current driving state.

---

## Robot-Body Exclusion

The current camera position can include part of Starlight itself in the frame.

Dark chassis or wiring pixels could otherwise resemble track features.

The vision system therefore excludes the robot-body region from relevant detection processing.

Conceptually:

```text
Camera image
      ↓
Useful region?
   ↙       ↘
 YES        NO
 ↓           ↓
Process     Ignore
```

A vision threshold should not be expected to compensate for pixels that should never have been considered navigation information.

---

# HSV + LAB Colour Processing

The final vision system uses both:

```text
HSV
LAB
```

where useful.

HSV provides useful hue, saturation and brightness separation.

LAB provides another representation of colour and lightness that can improve distinction under changing field conditions.

The final detector also considers:

- contour area;
- contour geometry;
- confidence conditions;
- region identity;
- morphological noise removal.

A colour match alone is therefore not automatically accepted as a valid navigation object.

---

# Field Calibration

The field calibration utility is:

```text
src/Cal_APOC.py
```

It allows the team to adjust LAB and HSV ranges while viewing the actual camera image and mask.

Recommended workflow:

```text
Mount final camera
      ↓
Place robot on competition-style field
      ↓
Allow camera exposure to settle
      ↓
Show known target colour
      ↓
Adjust LAB / HSV ranges
      ↓
Check near and far observations
      ↓
Check neighbouring / competing colours
      ↓
Retain values with that camera configuration
```

Colour calibration is linked to:

- lighting;
- camera position;
- camera angle;
- exposure;
- white balance;
- physical field material.

Changing one of these conditions may require recalibration.

---

# Parking Dependencies

The final parking controller is:

```text
src/parking_final.py
```

Its documented supporting interfaces include:

```text
src/heading.py
src/TOF_22.py
src/drive.py
```

Parking combines several different observations:

| Information | Source |
| --- | --- |
| Parking / wall geometry | Camera |
| Orientation | MPU6050 |
| Nearby physical gap | VL53L0X sensors |
| Vehicle movement | Encoder / drive interface |
| Steering state | Servo / drive interface |

No single sensor answers all of these questions.

---

## Parking Logic

The parking sequence combines:

```text
Approach
    ↓
Align
    ↓
Read distance
    ↓
Confirm
    ↓
Adjust
    ↓
Final distance condition
    ↓
Stop parallel to magenta wall
```

Distance confirmation uses repeated short-range observations rather than blindly acting on the first qualifying sample.

This helps reduce transitions caused by one transient reading.

---

## Heading and Distance Are Different

Heading answers:

```text
Which direction is the robot facing?
```

Distance answers:

```text
How large is the local gap?
```

A vehicle can have the correct heading while still being too close to a wall.

Likewise, a suitable gap does not prove the robot is parallel.

Parking therefore combines both measurements.

---
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

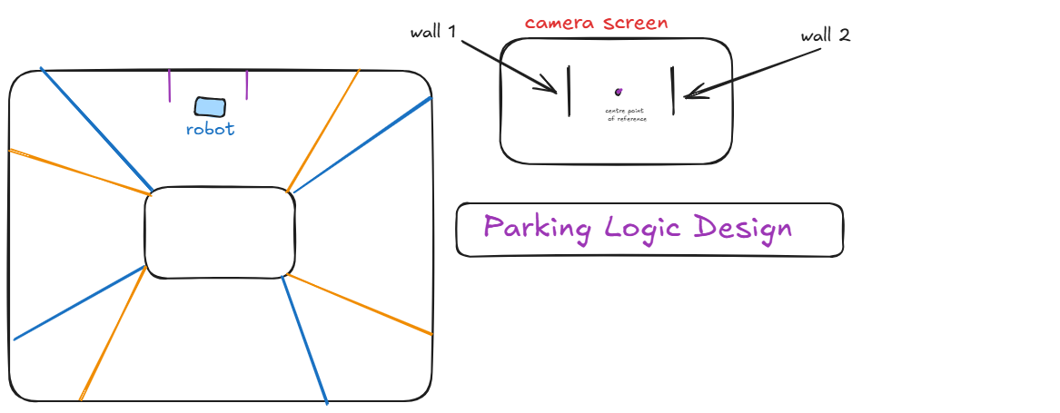
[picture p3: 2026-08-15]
other/Parking Logic Designing.png

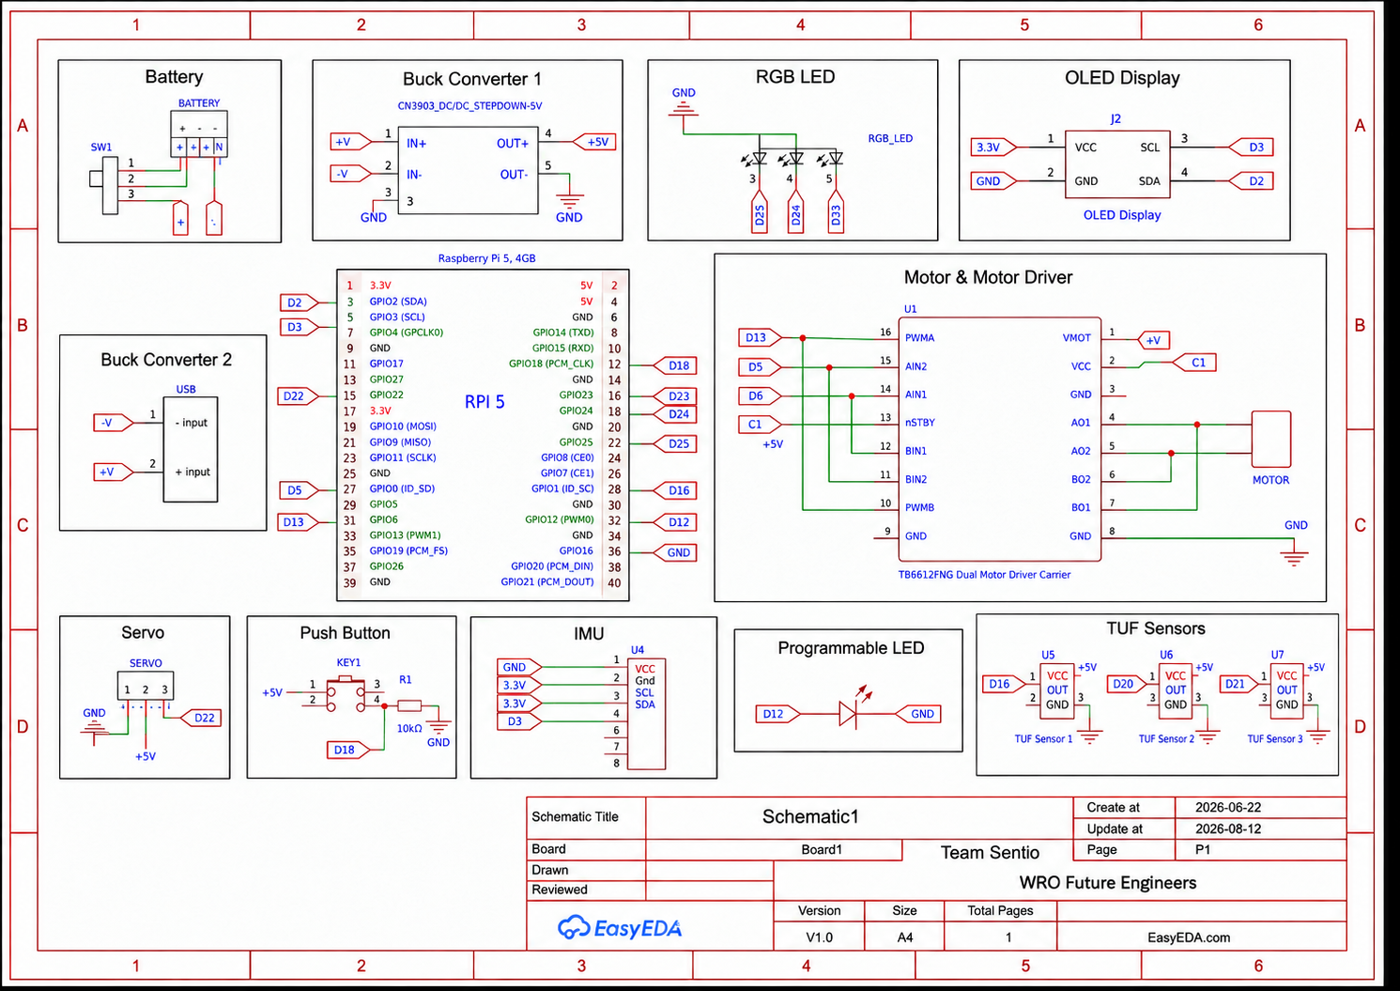
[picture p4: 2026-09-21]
Schemes/circuit_diagram.png

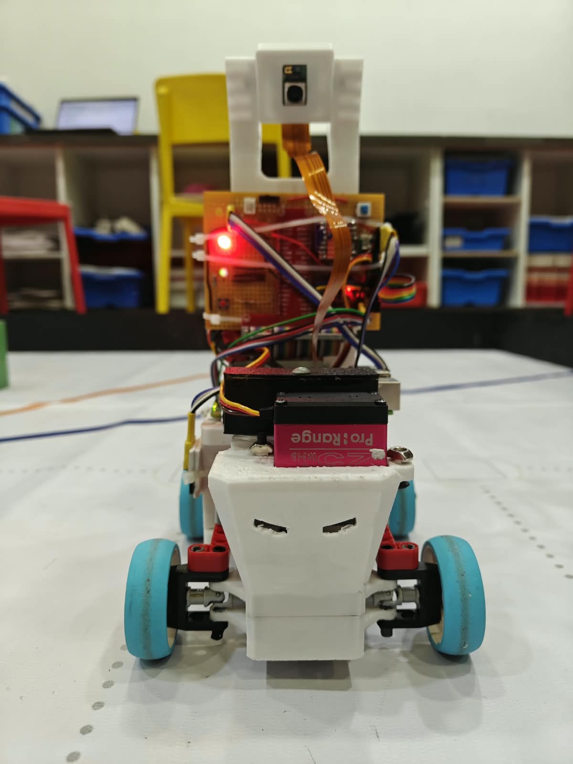
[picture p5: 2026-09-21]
v-photos/front view (1).jpg

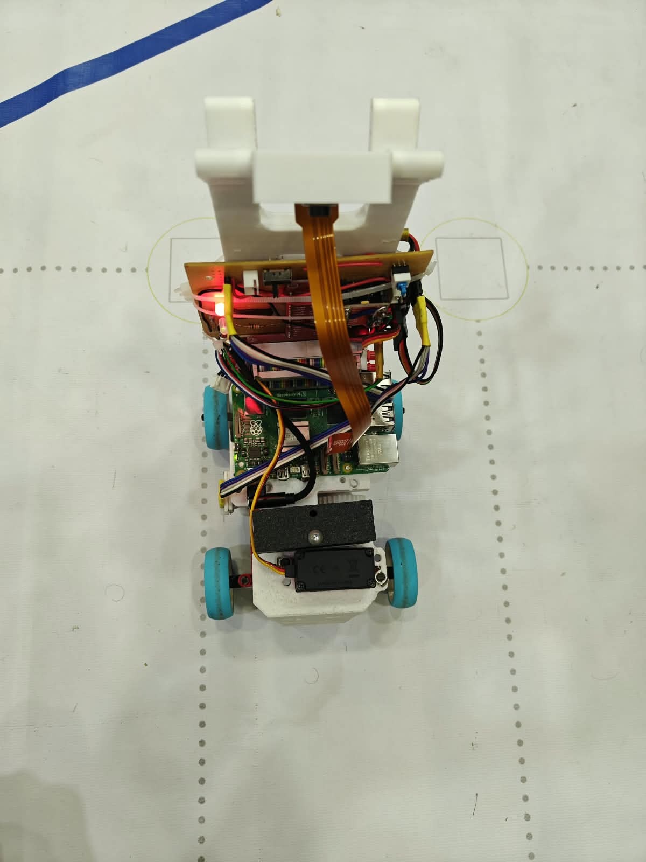
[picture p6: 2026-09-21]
v-photos/bird's eye view.jpg

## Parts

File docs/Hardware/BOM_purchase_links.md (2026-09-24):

# Starlight Bill of Materials

**Team:** Sentio 6010  
**Robot:** Starlight  
**Competition:** WRO Future Engineers 2026  
**Configuration:** APOC / Revision 27  
**Last updated:** 22 September 2026

---

## Configuration Status

This document describes the **current physical Starlight configuration** used after the post-Nationals redesign.

The authoritative current configuration is:

```text
COMPUTE      : Raspberry Pi 5, 4 GB
VISION       : 2 × Raspberry Pi Camera Module 3 Wide
RANGE        : 3 × VL53L0X Time-of-Flight sensors
ORIENTATION  : MPU6050-based heading sensor
DRIVE MOTOR  : 12 V geared DC encoder motor, nominal 600 RPM
ENCODER      : integrated quadrature encoder
STEERING     : DS3225 servo + Ackermann linkage
DRIVER       : TB6612FNG
BATTERY      : 3S LiPo, 11.1 V, 2200 mAh
DRIVE        : mechanical 4WD
DIFFERENTIAL : mechanical differential
GEAR STAGE   : 1:1 external gearing
START SYSTEM : one main power switch + one Start button
CHASSIS      : custom printed structure + LEGO Technic mechanisms
```

> [!IMPORTANT]
> Earlier references to a **1000 RPM Rhino motor**, **two ToF sensors**, **325 encoder counts per output revolution**, or a **36T → 24T current drivetrain ratio** are historical development information.
>
> They do **not** describe the current Revision 27 robot.

---

# 1. Current Competition Robot

## Core Electronics and Motion Hardware

| Qty. | Component | Current role on Starlight | Purchase link / source |
| ---: | --- | --- | --- |
| 1 | **Raspberry Pi 5, 4 GB** | Main computer running vision, sensor interfaces, challenge logic and control | [Robu.in](https://robu.in/product/raspberry-pi-5-model-4gb/) |
| 2 | **Raspberry Pi Camera Module 3 Wide** | Track, obstacle and parking perception | [Robu.in](https://robu.in/product/raspberry-pi-camera-module-3-wide/) |
| 3 | **VL53L0X Time-of-Flight distance sensor breakout** | Short-range physical gap measurement during parking and wall-relative movement | [Robokits India](https://robokits.co.in/sensors/lidar-laser-rangefinders/tiny-lidar-laser-ranging-sensor-tof-based-on-vl53l0x-2-meters-range) |
| 1 | **12 V geared DC encoder motor, nominal 600 RPM** | Main drivetrain motor | **Current installed motor. Exact SKU / purchase URL should be confirmed from the physical motor before final hardware freeze.** |
| 1 | **Integrated quadrature encoder** | Reports drive-motor shaft rotation and direction | Integrated into current 600 RPM motor |
| 1 | **TB6612FNG motor-driver module** | Motor direction and PWM control | [Robu.in](https://robu.in/product/motor-driver-tb6612fng-module-performance-ultra-small-volume-3-pi-matching-performance-ultra-l298n/) |
| 1 | **DS3225 25 kg-cm digital servo, 180°** | Front Ackermann steering | [Robu.in](https://robu.in/product/pro-range-ds3225-25kgcm-metal-gear-digital-servo-motor-180-degree/) |
| 1 | **MPU6050-based 10DOF module** | Gyro input for relative-heading estimation | [Robu.in](https://robu.in/product/mpu6050hmc5883lbmp180-10dof-3-axis-gyro-3-axis-acceleration-3-axis-magnetic-field-air-pres/) |
| 1 | **MicroSD card** | Raspberry Pi OS, code and calibration files | [Amazon.in](https://www.amazon.in/gp/product/B08L5HMJVW) |
| 1 | **Main power switch** | Isolates complete vehicle power | Source locally |
| 1 | **Momentary Start push button** | Starts autonomous operation after initialization | Source locally |
| 1 | **Status / illumination LED** | Status indication and/or illumination where retained | Source locally |

---

## Current vs Historical Hardware

| Item | Current Rev27 | Historical / superseded |
| --- | --- | --- |
| Drive motor | **600 RPM geared encoder motor** | Rhino GB37 RMCS-4091 / 1000 RPM reference |
| External gearing | **1:1** | 36T → 24T, ratio 1.5 |
| ToF sensors | **3 × VL53L0X** | 2 × VL53L0X |
| Encoder calibration | **Installed encoder must be calibrated** | 325 counts/output revolution worked example |
| Parking sensing | **Camera + IMU + 3 ToF + movement feedback** | Camera + IMU / dual-ToF development architecture |

---

# 2. Current Drive Motor and Encoder

The current competition drivetrain uses:

```text
12 V geared DC motor
Nominal gearbox-output speed: 600 RPM
Integrated quadrature encoder
External drivetrain ratio: 1:1
```

The motor provides propulsion while the encoder provides shaft-motion feedback.

---

## Encoder Role

The encoder supports:

- drive-response testing;
- movement repeatability;
- direction detection;
- encoder-targeted movement;
- stall or no-motion detection;
- comparison of commanded and observed drivetrain movement.

Conceptually:

```text
Movement request
      ↓
Motor command
      ↓
Encoder pulses
      ↓
Count / direction
      ↓
Target reached?
   ↙       ↘
 No        Yes
 ↓          ↓
Continue    Stop
```

---

## Encoder Calibration Rule

Do **not** document:

```text
325 counts/output revolution
```

as a specification of the current motor unless it has actually been measured or confirmed for the installed unit.

That value belongs to the older 1000 RPM supplier example.

The current installed encoder should instead be characterized using:

```text
src/encoder_test.py
```

Record:

```text
encoder counting mode
edges counted per cycle
count direction
counts per gearbox-output revolution
repeatability
```

before using a physical distance-per-count conversion.

---

## Encoder Electrical Interface

The encoder interface should provide:

```text
Channel 1
Channel 2
Encoder power
Ground
```

The Raspberry Pi and encoder must share an appropriate signal reference.

> [!CAUTION]
> Encoder supply voltage alone does not prove that its output signal is safe for direct Raspberry Pi GPIO.
>
> Verify actual encoder output levels on the installed motor before connecting the signals directly.

Route encoder signal wiring away from high-current motor wiring where practical.

---

# 3. Three VL53L0X Distance Sensors

Starlight now uses:

```text
3 × VL53L0X
```

as permanent competition sensors.

| Qty. | Sensor | Current role | Purchase link |
| ---: | --- | --- | --- |
| 3 | **VL53L0X ToF breakout** | Local distance measurement during parking, stopping and wall-relative movement | [Robokits India](https://robokits.co.in/sensors/lidar-laser-rangefinders/tiny-lidar-laser-ranging-sensor-tof-based-on-vl53l0x-2-meters-range) |

These sensors complement the cameras rather than replacing visual perception.

---

## Why Three ToF Sensors?

Each sensor provides information about a local physical gap.

The architecture separates:

```text
CAMERA
→ What feature is visible?

IMU
→ How much has the robot turned?

ENCODER
→ How much has the drivetrain moved?

TOF
→ How far away is the nearby physical surface?
```

The value of the sensor stack comes from these different measurements being used together.

---

# 4. Three-Sensor I2C Architecture

VL53L0X sensors begin with the same default I2C address.

Three sensors therefore cannot simply be enabled simultaneously and expected to identify themselves individually.

Starlight uses dedicated **XSHUT** lines:

| ToF | XSHUT GPIO |
| --- | ---: |
| **ToF 1** | GPIO16 |
| **ToF 2** | GPIO20 |
| **ToF 3** | GPIO21 |

All three share the main I2C bus:

```text
SDA → GPIO2
SCL → GPIO3
```

---

## Startup Sequence

```text
Power on
   ↓
Hold ToF 1 OFF
Hold ToF 2 OFF
Hold ToF 3 OFF
   ↓
Enable ToF 1
   ↓
Assign unique I2C address
   ↓
Enable ToF 2
   ↓
Assign unique I2C address
   ↓
Enable ToF 3
   ↓
Assign unique I2C address
   ↓
Verify all three sensors
   ↓
Enter waiting state
```

The distance-sensor hardware test is:

```text
src/TUF_test.py
```

---

## ToF Harness Requirements

Provide:

- shared SDA;
- shared SCL;
- appropriate shared supply;
- common ground;
- separate XSHUT line for each sensor;
- labelled sensor connectors;
- rigid sensor mounts;
- repeatable sensor orientation.

The software identifier and physical sensor must remain matched after repairs.

---

# 5. ToF Mechanical Integration

Each VL53L0X requires a rigid mount.

The mount determines **which physical surface the sensor measures**.

Check that:

- the optical aperture is unobstructed;
- no chassis edge enters the useful sensing path;
- wiring cannot move in front of the sensor;
- the sensor cannot rotate inside the mount;
- the intended wall or parking reference remains inside the useful measurement region.

The current chassis therefore uses:

```text
3 × ToF sensor positions
```

rather than the earlier two-sensor arrangement.

---

# 6. Current Sensor-Fusion Architecture

The Revision 27 architecture is:

```text
CAMERAS  = field appearance + image geometry
TOF ×3   = direct short-range distance
IMU      = relative heading / turn information
ENCODER  = drivetrain shaft movement
PI       = state logic + perception + control
DRIVER   = propulsion direction + PWM
SERVO    = Ackermann steering
```

---

## Sensor Roles

| Sensor | Primary question |
| --- | --- |
| Camera Module 3 Wide ×2 | What track, wall, pillar or parking feature is visible? |
| VL53L0X ×3 | How far away is the nearby physical surface? |
| MPU6050 | How much has the robot turned? |
| Motor encoder | How much has the drive shaft rotated and in which direction? |

No sensor is treated as a perfect substitute for another.

---

# 7. Current Drivetrain

Starlight uses:

```text
Drive type     : mechanical 4WD
Drive motor    : 12 V geared encoder motor, 600 RPM
External ratio : 1:1
Differential   : mechanical differential
Feedback       : integrated quadrature encoder
Steering       : front Ackermann
```

---

## 1:1 External Gearing

The current external drivetrain ratio is:

\[
G = 1
\]

Therefore, ideally:

```text
1 motor gearbox-output revolution
             ↓
1 wheel-transmission revolution
```

The exact current gear tooth counts should follow the physically installed drivetrain.

Do not describe the historical:

```text
36T driving → 24T driven
```

pair as the current gear stage.

That historical configuration gave:

\[
G = \frac{36}{24} = 1.5
\]

and was a speed-increasing drivetrain configuration.

---

## Why the Current Ratio Changed

The current 1:1 arrangement prioritizes:

- wheel torque;
- controllability;
- drivetrain operating margin;
- reliable acceleration;
- repeatable motion.

over maximum theoretical speed.

This decision followed earlier high-load and stall behaviour.

---

# 8. Mechanical Differential

A turn requires the inside and outside wheels to travel different distances.

```text
Outer wheel
→ longer path

Inner wheel
→ shorter path
```

The mechanical differential allows driven sides to rotate at different speeds while receiving propulsion from the same motor.

This works together with Ackermann steering:

```text
ACKERMANN
→ different steering angles

DIFFERENTIAL
→ different wheel speeds

ENCODER
→ drive-source rotation feedback
```

---

# 9. Steering Hardware

| Item | Current role |
| --- | --- |
| **DS3225 servo** | Steering actuator |
| **Ackermann linkage** | Produces different inside/outside steering angles |
| **LEGO / printed links** | Mechanical steering transmission |
| **Software steering clamp** | Prevents excessive servo travel |

Published control interface:

```text
Servo signal: GPIO22
PWM: 50 Hz
```

Calibration values should follow the physically tested final source.

Servo command values are **not** measured road-wheel angles.

---

# 10. Camera Hardware

Starlight uses:

```text
2 × Raspberry Pi Camera Module 3 Wide
```

The current mechanical arrangement places the cameras in repeatable rigid mounts designed around the final field geometry.

The documented viewing direction is approximately:

```text
60° from horizontal
```

Camera pose affects:

- ROI geometry;
- wall location in the frame;
- pillar appearance;
- marker detection;
- parking geometry.

The mount is therefore part of the sensing system, not decorative structure.

---

# 11. Power System

| Qty. | Component | Purpose | Purchase link / status |
| ---: | --- | --- | --- |
| 1 | **3S LiPo, 11.1 V, 2200 mAh** | Main energy source | [Amazon.in](https://www.amazon.in/PRAYOG-INDIA-ROBOTICS-Rechargeable-Connector/dp/B0H9L6B694) |
| 1 | **LiPo balance charger** | Charging and cell balancing | [Amazon.in](https://www.amazon.in/Pro3D-B6-AC-Battery-Balance-Charger/dp/B0CV9H28MQ) |
| 1 | **Regulated 5 V Raspberry Pi supply, approximately 5 A** | Main computer rail | Exact installed unit should be recorded |
| 1 | **5 V / 3 A buck converter / BEC** | Auxiliary regulated rail where used | [Robu.in](https://robu.in/product/ultra-small-size-dc-dc-5v-3a-bec-power-supply-buck-step-down-module/) |
| 1 | **Main power switch** | Main vehicle isolation | Source locally |
| — | Distribution wiring / terminals | Power distribution | Installed wiring |
| — | Battery connector pair | Battery connection | Match installed pack |
| — | Heat-shrink / insulation | Electrical protection | Source locally |

---

## Power Validation

Test the regulated electronics rail with:

```text
Raspberry Pi active
+
both cameras active
+
all three ToF sensors ranging
+
MPU6050 active
+
encoder active
+
servo moving
+
motor accelerating
```

Earlier undervoltage behaviour is one reason the higher-current Pi supply was retained.

---

# 12. Structural and Manufacturing Materials

Starlight combines custom printed structures with LEGO Technic mechanisms.

| Item | Purpose |
| --- | --- |
| **PLA / final print material** | Chassis, electronics structure and sensor mounts |
| **Rigid camera mounts** | Preserve calibrated camera pose |
| **3 × rigid ToF mounts** | Preserve range-sensor direction |
| **Motor mount / bracket** | Secure current 600 RPM motor |
| **Motor-to-drivetrain coupling** | Transfer motor output to mechanical transmission |
| **Electronics mounts** | Secure Raspberry Pi and electrical hardware |
| **Fasteners** | Printed-part and electronics assembly |
| **Perfboard / distribution board** | Electrical mounting where used |
| **Hook-up wire / ribbon cable** | Signal and power distribution |
| **Cable ties / heat-shrink** | Cable management and protection |

See:

```text
Models/
```

for current mechanical model files.

---

# 13. LEGO Technic Drivetrain Components

LEGO Technic parts are retained where serviceability and mechanical adjustment are useful.

| Component | Role | Reference |
| --- | --- | --- |
| **2 × 4 L Beam** | Compact mechanical support | [BrickLink](https://www.bricklink.com/v2/catalog/catalogitem.page?P=32140) |
| **Half bush** | Axle spacing / retention | [BrickLink](https://www.bricklink.com/v2/catalog/catalogitem.page?P=4265c&idColor=3) |
| **Bush** | Axle retention | [BrickLink](https://www.bricklink.com/v2/catalog/catalogitem.page?P=3713) |
| **2L axle connector** | Joins shaft sections | [BrickLink](https://www.bricklink.com/v2/catalog/catalogitem.page?P=6538c) |
| **28-tooth differential** | Allows unequal driven-wheel speed | [BrickLink](https://www.bricklink.com/v2/catalog/catalogitem.page?P=73071) |
| **24-tooth gear** | Retained drivetrain inventory / historical or other transmission use | [BrickLink](https://www.bricklink.com/v2/catalog/catalogitem.page?P=3648) |
| **20-tooth gear** | Intermediate drivetrain use where installed | [BrickLink](https://www.bricklink.com/v2/catalog/catalogitem.page?P=32269) |
| **12-tooth bevel gear** | Compact direction-changing transmission | [BrickLink](https://www.bricklink.com/v2/catalog/catalogitem.page?P=6589) |
| **9-unit beam** | Drivetrain structure | [BrickLink](https://www.bricklink.com/v2/catalog/catalogitem.page?P=40490) |
| **5L axle** | Drivetrain shaft | [BrickLink](https://www.bricklink.com/v2/catalog/catalogitem.page?id=540&idColor=86) |
| **6L axle** | Drivetrain shaft | [BrickLink](https://www.bricklink.com/v2/catalog/catalogitem.page?P=3706&idColor=60) |
| **4L axle with stop** | Shaft positioning | [BrickLink](https://www.bricklink.com/v2/catalog/catalogitem.page?id=90241&idColor=85) |
| **Smooth pin** | Beam connection / pivot | [BrickLink](https://www.bricklink.com/v2/catalog/catalogitem.page?P=3673) |
| **Universal joint** | Rotation transfer between non-collinear shafts | [BrickLink](https://www.bricklink.com/v2/catalog/catalogitem.page?P=62520c01) |
| **43 × 14 wheel / tyre assembly** | Wheel contact | [BrickLink](https://www.bricklink.com/v2/catalog/catalogitem.page?P=65834pb02) |

> [!NOTE]
> The exact pair of external gears forming the **current 1:1 ratio** should be recorded from the installed Rev27 drivetrain.
>
> Do not label the older 36T → 24T speed-increasing pair as current.

---

# 14. Current Wiring Baseline

| Function | Current interface |
| --- | --- |
| Motor direction | GPIO5 / GPIO6 |
| Motor PWM | GPIO13 |
| Motor PWM frequency | 1 kHz |
| Steering servo | GPIO22 |
| Steering PWM frequency | 50 Hz |
| I2C SDA | GPIO2 |
| I2C SCL | GPIO3 |
| MPU6050 | I2C address `0x68` |
| ToF 1 XSHUT | GPIO16 |
| ToF 2 XSHUT | GPIO20 |
| ToF 3 XSHUT | GPIO21 |
| Encoder | Integrated C1 / C2 channels |

See:

```text
wiring-guide.md
```

for complete wiring.

---

# 15. Harness Checklist

## Power and Actuation

- [ ] Battery connector secure
- [ ] Motor wiring secured
- [ ] Main switch installed
- [ ] Raspberry Pi regulated supply connected
- [ ] Servo power and signal secure
- [ ] Motor-driver PWM and direction wiring secure
- [ ] Common grounds verified
- [ ] Heat-shrink / insulation fitted
- [ ] High-current wiring strain-relieved

## Cameras and I2C

- [ ] Camera 1 ribbon secured
- [ ] Camera 2 ribbon secured
- [ ] SDA / SCL wiring secure
- [ ] MPU6050 connection verified
- [ ] ToF 1 power / SDA / SCL / XSHUT verified
- [ ] ToF 2 power / SDA / SCL / XSHUT verified
- [ ] ToF 3 power / SDA / SCL / XSHUT verified
- [ ] GPIO16 / GPIO20 / GPIO21 labels verified
- [ ] All ToF connectors labelled physically
- [ ] Sensor orientation matches software naming

## Encoder

- [ ] Motor power wires secure
- [ ] Encoder supply correct
- [ ] Encoder ground connected
- [ ] Encoder channel 1 verified
- [ ] Encoder channel 2 verified
- [ ] Count direction verified
- [ ] Logic-level compatibility verified
- [ ] Signal wiring routed away from motor wiring where practical

---

# 16. Component Tests

Before a full run:

```text
Steering   → src/servo_test.py
Encoder    → src/encoder_test.py
ToF ×3     → src/TUF_test.py
Heading    → src/heading.py
Vision     → src/Cal_APOC.py
```

Recommended order:

```text
Mechanical inspection
        ↓
Power inspection
        ↓
Steering test
        ↓
Encoder test
        ↓
ToF test
        ↓
Heading test
        ↓
Camera calibration
        ↓
Low-speed integrated run
        ↓
Full challenge
```

---

# 17. Competition Controls

The current physical control system includes:

```text
1 × main power switch
1 × momentary Start button
```

Expected startup flow:

```text
ROBOT OFF
   ↓
Main switch ON
   ↓
Raspberry Pi boots
   ↓
Cameras initialize
   ↓
IMU initializes
   ↓
Encoder initializes
   ↓
Three ToF sensors receive separate addresses
   ↓
WAITING STATE
   ↓
Start button
   ↓
Autonomous motion
```

Always confirm the final hardware against the current official WRO Future Engineers rules and event Q&A before competition.

---

# 18. APOC Spares Pack

| Spare | Suggested qty. | Reason |
| --- | ---: | --- |
| **Current 600 RPM encoder motor** | 1 | High-impact drivetrain spare |
| **VL53L0X ToF sensor** | 2–3 | Small and easy to damage or miswire |
| **TB6612FNG motor driver** | 1–2 | Drive-stage replacement |
| **DS3225 steering servo** | 1 | Steering-critical component |
| **Camera Module 3 Wide** | 1 | Shared spare |
| **Camera ribbon cable** | 2+ | Frequent physical failure point |
| **MicroSD card with tested image/code** | 1 | Fast software recovery |
| **5 V regulator / BEC** | 1 | Power-system spare |
| **Main power switch** | 1 | Mechanical spare |
| **Start push button** | 1 | Control spare |
| **Motor / encoder harness** | 1 | Fast drivetrain replacement |
| **ToF harness / leads** | 2–3 | Fast range-sensor replacement |
| **Fasteners / bushes / axles / gears** | Assorted | Mechanical repairs |
| **Wire / solder / heat-shrink / cable ties** | Assorted | Electrical repairs |

---

# 19. Development Equipment

These items are useful during setup but are not permanent robot payload.

| Component | Purpose |
| --- | --- |
| Keyboard + mouse | Local Pi setup |
| External monitor | Bench debugging |
| Micro-HDMI cable | Raspberry Pi display |
| USB logic analyser | Encoder / I2C diagnosis |
| Digital multimeter | Voltage, continuity and signal checks |
| Bench supply | Controlled electrical testing |
| Laptop | Git, SSH, calibration and code |
| 3D printer | Sensor / camera / chassis parts |
| Vernier caliper | Dimensional checks |
| Digital scale | Final robot mass check |

---

# 20. Historical / Superseded Hardware

Historical components are retained here for traceability.

They must not be confused with the current competition configuration.

| Historical item | Status | Current replacement |
| --- | --- | --- |
| **Rhino GB37 RMCS-4091, 1000 RPM-class encoder motor** | Historical supplier / development reference | **Current 600 RPM encoder motor** |
| **325 counts/output revolution** | Worked example from historical motor specification | **Installed current encoder calibration** |
| **36T → 24T external gearing, ratio 1.5** | Historical speed-increasing drivetrain | **Current 1:1 gearing** |
| **Two VL53L0X sensors** | Earlier APOC development state | **Three VL53L0X sensors** |
| **Dual-ToF sensor fusion** | Earlier architecture | **Three-ToF architecture** |
| Camera + IMU-only parking information | Superseded | Camera + heading + three ToF + drivetrain feedback |

---

## Historical 1000 RPM Motor Reference

The older BOM used:

```text
Rhino GB37 RMCS-4091
12 V
1000 RPM class
integrated encoder
```

Historical supplier link:

[Robokits India — Rhino GB37 RMCS-4091](https://robokits.co.in/motors/rhino-gb37-12v-dc-geared-motor/dc-12v-encoder-servo-motors/rhino-gb37-12v-1000rpm-0.7kgcm-dc-geared-encoder-servo-motor)

This link is retained only so older:

- calculations;
- commits;
- photographs;
- design notes

remain understandable.

It is **not the current competition motor specification**.

---

# 21. Pre-Event Hardware Freeze Checklist

Before declaring the APOC hardware configuration frozen:

- [ ] current motor confirmed as nominal **600 RPM**
- [ ] exact motor model / SKU recorded
- [ ] exact motor purchase URL recorded
- [ ] motor mount secure
- [ ] current external gear ratio confirmed as **1:1**
- [ ] drivetrain rotates freely
- [ ] differential operates correctly
- [ ] all four driven wheels receive propulsion
- [ ] encoder direction confirmed
- [ ] current encoder counts/revolution physically calibrated
- [ ] no historical 325-count assumption used without verification
- [ ] **three** VL53L0X sensors physically installed
- [ ] ToF 1 initializes from cold boot
- [ ] ToF 2 initializes from cold boot
- [ ] ToF 3 initializes from cold boot
- [ ] GPIO16 / GPIO20 / GPIO21 XSHUT sequence works
- [ ] each ToF receives a unique address automatically
- [ ] all sensor labels match software identifiers
- [ ] both cameras initialize
- [ ] camera mounts cannot shift
- [ ] Pi supply passes full-load test
- [ ] no undervoltage warning during normal integrated operation
- [ ] steering travels without binding
- [ ] no wire can enter gears, wheels or steering linkage
- [ ] main power switch functions correctly
- [ ] Start button functions correctly
- [ ] robot boots into waiting state automatically
- [ ] spare SD card boots
- [ ] spare hardware has been tested
- [ ] `bom.md` matches the physical robot
- [ ] `wiring-guide.md` matches the physical robot
- [ ] `drivetrain.md` matches the physical robot
- [ ] engineering journal matches the physical robot
- [ ] GitHub source matches the Raspberry Pi source

---

# 22. Purchase / Verification Priority

## Already Part of the Current Architecture

1. Raspberry Pi 5, 4 GB
2. Camera Module 3 Wide ×2
3. VL53L0X ×3
4. DS3225 servo
5. TB6612FNG motor driver
6. MPU6050 module
7. 3S 11.1 V battery
8. encoder-equipped 600 RPM motor
9. main power switch
10. Start button

## Items That Must Be Explicitly Verified Before Freeze

1. **Exact manufacturer / SKU of the current 600 RPM motor**
2. **Exact current motor purchase link**
3. **Installed encoder count convention**
4. **Measured counts per gearbox-output revolution**
5. **Exact current 1:1 gear tooth-count pair**
6. **Exact high-current 5 V regulator**
7. **Exact ToF breakout revision if different from linked board**

Do not replace missing information with a specification from an older part merely because the number is conveniently available.

---

# 23. Source-Link Maintenance

When maintaining this BOM:

1. Link to the **actual component installed**.
2. Keep superseded components in the historical section.
3. Never copy a motor specification onto a different motor.
4. Never copy encoder counts from an old encoder onto the current encoder.
5. Keep current and historical gearing clearly separated.
6. Update ToF quantity everywhere if the sensor architecture changes.
7. Keep XSHUT GPIO assignments synchronized with the wiring guide and source code.
8. Update photographs after major mechanical changes.
9. Update the BOM whenever the physical robot changes.
10. Record the date of every configuration freeze.

---

# 24. Technical References

### Current project references

- `docs/hardware/drivetrain.md`
- `docs/hardware/wiring-guide.md`
- `docs/software/Software_Dependencies.md`
- `docs/testing.md`
- `docs/engineering-decisions.md`
- `docs/failure-log.md`
- `docs/development/apoc-hardware-update.md`
- `src/encoder_test.py`
- `src/TUF_test.py`
- `src/servo_test.py`
- `src/heading.py`

### Component references

- [Raspberry Pi 5](https://robu.in/product/raspberry-pi-5-model-4gb/)
- [Raspberry Pi Camera Module 3 Wide](https://robu.in/product/raspberry-pi-camera-module-3-wide/)
- [VL53L0X breakout](https://robokits.co.in/sensors/lidar-laser-rangefinders/tiny-lidar-laser-ranging-sensor-tof-based-on-vl53l0x-2-meters-range)
- [DS3225 servo](https://robu.in/product/pro-range-ds3225-25kgcm-metal-gear-digital-servo-motor-180-degree/)
- [TB6612FNG](https://robu.in/product/motor-driver-tb6612fng-module-performance-ultra-small-volume-3-pi-matching-performance-ultra-l298n/)
- [MPU6050-based 10DOF module](https://robu.in/product/mpu6050hmc5883lbmp180-10dof-3-axis-gyro-3-axis-acceleration-3-axis-magnetic-field-air-pres/)

### Historical motor reference

- [Rhino GB37 RMCS-4091 1000 RPM-class motor](https://robokits.co.in/motors/rhino-gb37-12v-dc-geared-motor/dc-12v-encoder-servo-motors/rhino-gb37-12v-1000rpm-0.7kgcm-dc-geared-encoder-servo-motor)

---

# Final Reproduction Snapshot

```text
ROBOT        : Starlight
TEAM         : Team Sentio 1747
COMPETITION  : WRO Future Engineers 2026 / APOC

COMPUTE      : Raspberry Pi 5, 4 GB
VISION       : 2 × Raspberry Pi Camera Module 3 Wide
RANGE        : 3 × VL53L0X
ORIENTATION  : MPU6050
DRIVE MOTOR  : 12 V geared encoder motor, nominal 600 RPM
ENCODER      : integrated quadrature encoder
               installed count calibration required
STEERING     : DS3225 + Ackermann
DRIVER       : TB6612FNG
BATTERY      : 3S LiPo, 11.1 V, 2200 mAh
DRIVE        : mechanical 4WD
DIFFERENTIAL : mechanical differential
GEAR STAGE   : 1:1 external ratio
TOF XSHUT    : GPIO16 / GPIO20 / GPIO21
START SYSTEM : one power switch + one Start button
STRUCTURE    : printed chassis / mounts + LEGO Technic mechanisms
```

---

## Revision Note

This revision corrects the principal configuration conflicts in the previous BOM:

```text
2 ToF          → 3 ToF
1000 RPM motor → 600 RPM motor
1.5 gearing    → 1:1 gearing
325 counts/rev → historical only, not assigned to current encoder
dual ToF       → three-sensor ToF architecture
```

The 1000 RPM motor and 36T → 24T gearing remain documented only as **historical development references**.

---

**Team Sentio 1747**  
**Starlight**  
**WRO Future Engineers 2026**  
**Robofun Lab (RFL), India**

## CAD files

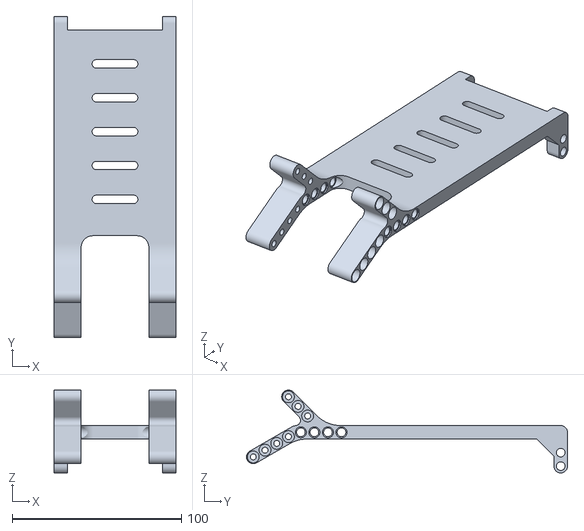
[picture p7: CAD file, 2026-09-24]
models/P1.STL
72.0 x 189.6 x 49.0

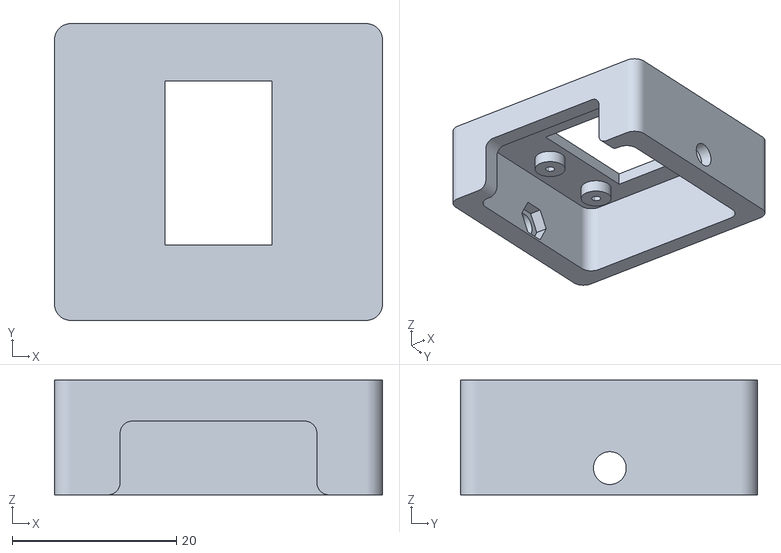
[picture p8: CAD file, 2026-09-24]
models/C2.stl
40.0 x 36.2 x 14.0

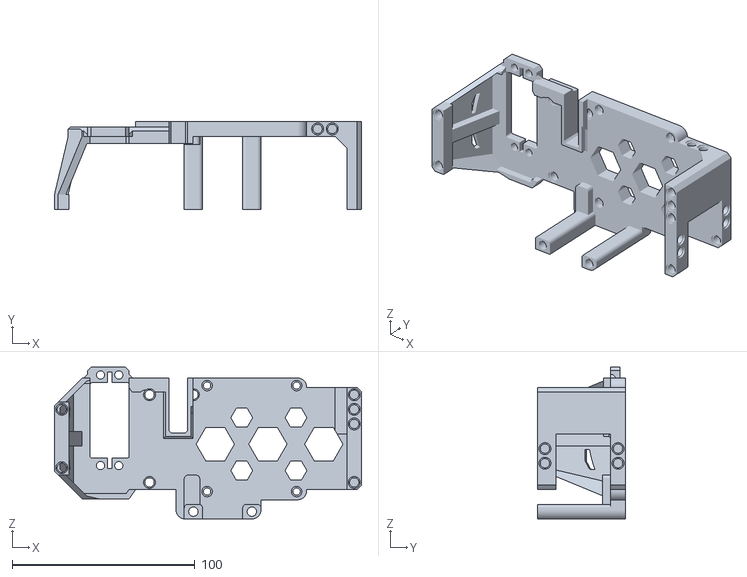
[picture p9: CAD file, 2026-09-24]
models/P2.STL
168.0 x 48.0 x 83.2

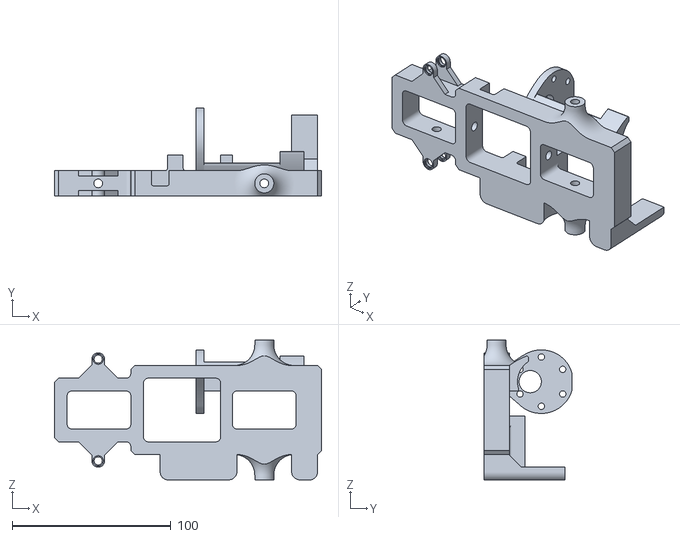
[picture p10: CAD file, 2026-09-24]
models/P3.STL
168.0 x 55.5 x 88.0

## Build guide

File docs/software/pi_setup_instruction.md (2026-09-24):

# Raspberry Pi Setup and Run Guide

## Team Sentio — WRO Future Engineers 2026

This document describes how to prepare a Raspberry Pi 5, install the required software, configure the cameras, MPU6050, encoder and three VL53L0X sensors, verify the motor and steering system, clone the Team Sentio repository, and run the competition software used by **Starlight**.

**Team:** Deyaan Agrawal, Darsh Zaveri, Aarav Jalan  
**Mentors:** Sunil Solanki, Shyam Satasiya  
**Robot:** Starlight  
**Competition:** World Robot Olympiad 2026 — Future Engineers  
**Institution / Training Environment:** Robofun Lab (RFL), India  
**Documentation Revision:** Revision 29, September 2026

The purpose of this guide is **reproducibility**.

A technically competent user should be able to start with a compatible Raspberry Pi 5, reproduce the software environment, connect the documented hardware, verify the required subsystems and understand how the current competition software is launched.

> [!IMPORTANT]
> The exact source running on the physically tested robot remains the authoritative competition version.
>
> The Raspberry Pi source, GitHub source, calibration values, wiring documentation and engineering journal should remain synchronized whenever the competition configuration changes.

---

# 1. Competition Computing Platform

The current Starlight computing and sensing system uses:

- Raspberry Pi 5, 4 GB
- Raspberry Pi OS
- Python 3
- 2 × Raspberry Pi Camera Module 3 Wide
- OpenCV
- NumPy
- Picamera2
- RPi.GPIO-compatible GPIO interface
- SMBus2 / I2C
- MPU6050 heading sensor
- 3 × VL53L0X time-of-flight sensors
- motor quadrature encoder
- TB6612FNG motor driver
- DS3225 steering servo
- 12 V geared DC encoder motor
- 3S 11.1 V LiPo battery
- regulated Raspberry Pi electronics supply

The current GitHub competition source directory is:

```text
src/
├── Cal_APOC.py
├── Final_Obstacle_Challenge.py
├── N_Vision_final.py
├── Sentio_Open_2026.py
├── openvision.py
├── TOF_22.py
├── TUF_test.py
├── drive.py
├── encoder_test.py
├── heading.py
├── parking_final.py
└── servo_test.py
```

The principal files have the following roles:

| File | Purpose |
|---|---|
| `Cal_APOC.py` | Interactive HSV / LAB field calibration |
| `Final_Obstacle_Challenge.py` | Main Obstacle Challenge controller |
| `N_Vision_final.py` | Multi-ROI obstacle, wall and course-colour vision |
| `Sentio_Open_2026.py` | Main Open Challenge controller |
| `openvision.py` | Open Challenge vision module |
| `TOF_22.py` | Three-VL53L0X initialization and distance interface |
| `TUF_test.py` | ToF communication and distance test |
| `drive.py` | Motor, steering and encoder interface |
| `encoder_test.py` | Encoder and movement test |
| `heading.py` | MPU6050 relative-heading calculation |
| `parking_final.py` | Parking controller |
| `servo_test.py` | Steering centre, direction and travel test |

---

# 2. Important Safety Information

Before configuring or running Starlight:

1. Switch the robot off before connecting or disconnecting cameras, GPIO wiring or I2C devices.
2. Confirm battery polarity before applying power.
3. Never connect the 3S LiPo voltage directly to the Raspberry Pi 5 V rail.
4. Use a properly regulated power supply for the Raspberry Pi.
5. The DC motor must be controlled through the motor driver and must never be connected directly to Raspberry Pi GPIO.
6. Ensure connected control electronics share the correct common electrical reference.
7. Check the steering linkage mechanically before powering the servo.
8. Raise the drive wheels or place the robot safely on the track before running motor tests.
9. Keep hands, tools and loose wires away from wheels, gears and the steering mechanism.
10. Keep a rapid power-disconnect method available during testing.
11. Charge the LiPo only with an appropriate balance charger and under supervision.
12. Do not change wiring while the battery is connected.
13. Do not increase steering travel without mechanically checking the Ackermann linkage.
14. Stop testing immediately if the Raspberry Pi reports repeated undervoltage warnings.

These checks are part of the normal setup process, not optional extras added after something starts smoking.

---

# 3. Install Raspberry Pi OS

Use **Raspberry Pi Imager** to install a current Raspberry Pi OS image compatible with the Raspberry Pi 5.

A Raspberry Pi OS installation with the graphical desktop is useful during development because the vision programs may use OpenCV display windows such as:

```python
cv2.imshow()
```

During Raspberry Pi Imager setup, configure as required:

- username;
- password;
- hostname;
- keyboard layout;
- locale;
- Wi-Fi.

After writing the image:

1. insert the storage device into the Raspberry Pi;
2. connect the required display, keyboard and mouse during setup;
3. boot the Raspberry Pi;
4. complete Raspberry Pi OS first-run configuration.

---

# 4. Record the Operating Environment

For reproducibility, record the operating-system and Python information:

```bash
cat /etc/os-release
```

```bash
uname -a
```

```bash
python3 --version
```

Optional package-state records:

```bash
python3 -m pip list
```

```bash
dpkg -l | grep -E "picamera2|opencv|numpy|smbus|gpio"
```

Exact package versions should not be invented retrospectively if they were not recorded from the physically tested environment.

---

# 5. Update Raspberry Pi OS

Open a terminal and run:

```bash
sudo apt update
sudo apt full-upgrade -y
```

Then reboot:

```bash
sudo reboot
```

After rebooting, open a terminal again.

---

# 6. Install Required Software

Install the principal Raspberry Pi OS packages:

```bash
sudo apt update

sudo apt install -y \
    git \
    python3-picamera2 \
    python3-opencv \
    python3-numpy \
    python3-smbus2 \
    i2c-tools
```

These packages provide:

| Package | Purpose |
|---|---|
| `git` | Clone and synchronize the repository |
| `python3-picamera2` | Raspberry Pi camera interface |
| `python3-opencv` | Computer vision |
| `python3-numpy` | Numerical and image-array processing |
| `python3-smbus2` | I2C communication |
| `i2c-tools` | I2C diagnostics |

Any additional package required by the exact final ToF or encoder source should be installed according to the imports in that tested source.

Verify Python:

```bash
python3 --version
```

---

# 7. Configure GPIO Support on Raspberry Pi 5

The Team Sentio drive software uses an interface compatible with:

```python
import RPi.GPIO as GPIO
```

First test the current environment:

```bash
python3 -c "import RPi.GPIO as GPIO; print('GPIO import OK')"
```

If this succeeds, continue.

If a Raspberry Pi 5 installation does not provide a working compatible interface, install:

```bash
sudo apt install -y python3-rpi-lgpio
```

Then verify again:

```bash
python3 -c "import RPi.GPIO as GPIO; print('GPIO interface OK')"
```

If a conflicting classic package is present:

```bash
sudo apt remove -y python3-rpi.gpio
sudo apt install -y python3-rpi-lgpio
```

Do not intentionally maintain conflicting packages that provide the same `RPi.GPIO` namespace.

---

# 8. Enable I2C

The MPU6050 and VL53L0X sensors use I2C.

Run:

```bash
sudo raspi-config
```

Navigate to:

```text
Interface Options
→ I2C
→ Enable
```

Exit and reboot:

```bash
sudo reboot
```

After reboot:

```bash
i2cdetect -y 1
```

---

# 9. Verify the MPU6050

The shared heading helper is:

```text
src/heading.py
```

The MPU6050 is expected on I2C bus 1 at:

```text
0x68
```

Scan:

```bash
i2cdetect -y 1
```

A correctly connected MPU6050 should normally appear as:

```text
68
```

If `68` does not appear:

- check MPU6050 power;
- check SDA;
- check SCL;
- check common ground;
- confirm I2C is enabled;
- inspect the connector;
- confirm the sensor is connected to the expected bus.

Do not run IMU-dependent manoeuvres until the connection is resolved.

---

# 10. MPU6050 Wiring

Typical connections are:

| MPU6050 | Raspberry Pi |
|---|---|
| VCC | appropriate sensor supply |
| GND | GND |
| SDA | GPIO2 / physical pin 3 |
| SCL | GPIO3 / physical pin 5 |

The final wiring should also be checked against:

```text
schemes/
docs/wiring_guide.md
```

The schematic takes precedence over a generic table if the final harness is documented more precisely there.

---

# 11. Main GPIO Configuration

The current documented control assignments are:

| Function | BCM GPIO | Physical Pin |
|---|---:|---:|
| Motor driver IN1 | GPIO5 | Pin 29 |
| Motor driver IN2 | GPIO6 | Pin 31 |
| Motor PWM | GPIO13 | Pin 33 |
| Steering servo | GPIO22 | Pin 15 |
| Encoder A | GPIO17 | Pin 11 |
| Encoder B | GPIO27 | Pin 13 |
| I2C SDA | GPIO2 | Pin 3 |
| I2C SCL | GPIO3 | Pin 5 |
| ToF 1 XSHUT | GPIO16 | Pin 36 |
| ToF 2 XSHUT | GPIO20 | Pin 38 |
| ToF 3 XSHUT | GPIO21 | Pin 40 |

The competition source remains authoritative if a late tested revision changes any assignment.

---

# 12. Motor Driver Configuration

The drive motor is controlled through the TB6612FNG motor-driver system.

The documented motor-control pins are:

```text
IN1  = GPIO5
IN2  = GPIO6
PWM  = GPIO13
```

The motor PWM baseline is:

```text
1000 Hz
```

Challenge controllers should request movement through the shared drive interface:

```python
drive.forward(speed)
drive.backward(speed)
drive.stop()
```

rather than reimplementing low-level GPIO control inside each challenge script.

---

# 13. Steering Servo Configuration

The DS3225 steering servo is controlled through:

```text
GPIO22
```

with a baseline PWM frequency of:

```text
50 Hz
```

The exact competition steering centre and travel limits are defined by the tested `src/drive.py`.

Do not copy an older centre, left limit or right limit into a new installation without checking the current source and the physical mechanism.

> [!CAUTION]
> Do not expand the steering range without inspecting the physical Ackermann linkage.
>
> Excessive steering travel can load the linkage, bind the mechanism or disconnect steering components.

Use the dedicated test:

```bash
python3 src/servo_test.py
```

before a full challenge run.

---

# 14. Encoder Configuration

The current drive motor includes a quadrature encoder.

Documented encoder pins are:

```text
Encoder A → GPIO17
Encoder B → GPIO27
```

The encoder is used for:

- movement feedback;
- checking direction;
- repeatable encoder-targeted movement;
- motor-response testing.

The encoder measures shaft motion, not exact ground displacement.

Wheel slip, tyre deformation and drivetrain play can make physical travel differ from shaft-based movement.

Use:

```bash
python3 src/encoder_test.py
```

to verify the current implementation.

---

# 15. Three VL53L0X Sensors

Starlight uses:

```text
3 × VL53L0X
```

The sensors share the I2C bus.

Because identical VL53L0X sensors begin with the same default address, their XSHUT lines are used to enable them sequentially and assign separate working addresses.

The documented XSHUT connections are:

```text
ToF 1 XSHUT → GPIO16
ToF 2 XSHUT → GPIO20
ToF 3 XSHUT → GPIO21
```

The current sensor interface is:

```text
src/TOF_22.py
```

The dedicated test program is:

```text
src/TUF_test.py
```

Run:

```bash
python3 src/TUF_test.py
```

Verify:

- all three sensors initialize;
- each sensor responds independently;
- distances change sensibly when an object is moved;
- physical sensor orientation matches the software meaning assigned to that sensor.

---

# 16. Camera Installation

Starlight uses:

```text
2 × Raspberry Pi Camera Module 3 Wide
```

Always power the Raspberry Pi off before connecting or reseating CSI cables.

The camera mounts should remain rigid.

Changing camera position can alter:

- visible wall geometry;
- contour position;
- marker timing;
- pillar apparent size;
- parking alignment;
- ROI validity.

The current engineering documentation describes a relatively downward-facing camera geometry, approximately:

```text
60° from horizontal
```

Treat camera pose as a mechanical calibration parameter, not merely a cosmetic mounting choice.

---

# 17. Verify Both Cameras

After connecting both cameras:

```bash
rpicam-hello --list-cameras
```

Both cameras should appear.

Test camera 0:

```bash
rpicam-hello --camera 0 --timeout 3000
```

Test camera 1:

```bash
rpicam-hello --camera 1 --timeout 3000
```

Confirm for each camera:

- image is visible;
- image orientation is correct;
- CSI ribbon is secure;
- lens is unobstructed;
- mount is rigid;
- no intermittent connection occurs.

Camera numbering must be verified on the physical Raspberry Pi before changing software indices.

---

# 18. Clone the Team Sentio Repository

From the Raspberry Pi terminal:

```bash
cd ~
```

Clone:

```bash
git clone https://github.com/teamsentiorobotics-svg/World-Robot-Olympiad---Team-Sentio-.git
```

Enter the repository:

```bash
cd World-Robot-Olympiad---Team-Sentio-
```

Check the root:

```bash
ls
```

The repository should contain items including:

```text
README.md
CHANGELOG.md
requirements.md
.gitattributes
.gitignore
Models/
docs/
schemes/
src/
t-photos/
v-photos/
videos/
other/
```

---

# 19. Verify the Competition Source Directory

Run:

```bash
ls src
```

The current documented source directory should contain:

```text
Cal_APOC.py
Final_Obstacle_Challenge.py
N_Vision_final.py
Sentio_Open_2026.py
openvision.py
TOF_22.py
TUF_test.py
drive.py
encoder_test.py
heading.py
parking_final.py
servo_test.py
```

Do not substitute older development filenames such as:

```text
open_challenge_final_ready_to_go.py
Obstacle_Challenge.py
openVision.py
vision.py
parking.py
```

unless the physically tested competition Raspberry Pi actually uses those files and the repository has deliberately been reverted to that architecture.

For Revision 29 documentation, the filenames listed above are the current documented names.

---

# 20. Record the Exact Git Revision

From the repository root:

```bash
git rev-parse HEAD
```

This returns the exact commit SHA.

Also run:

```bash
git status
```

For a frozen competition configuration, the preferred state is:

```text
nothing to commit, working tree clean
```

A physically tested source file should not exist only as an uncommitted Raspberry Pi edit while GitHub contains a different version.

---

# 21. Verify External Python Dependencies

From the repository root:

```bash
python3 - <<'PY'
import cv2
import numpy
import smbus2
import RPi.GPIO as GPIO
from picamera2 import Picamera2

print("OpenCV:", cv2.__version__)
print("NumPy:", numpy.__version__)
print("SMBus2: OK")
print("Picamera2: OK")
print("GPIO interface: OK")
print("Team Sentio external dependency check: PASS")
PY
```

The command should complete without an exception.

The ToF and encoder dependencies should also be tested through the actual competition source because their exact supporting packages must match the tested implementation.

---

# 22. Syntax-Check the Current Source

From the repository root:

```bash
python3 -m py_compile \
    src/Cal_APOC.py \
    src/Final_Obstacle_Challenge.py \
    src/N_Vision_final.py \
    src/Sentio_Open_2026.py \
    src/openvision.py \
    src/TOF_22.py \
    src/TUF_test.py \
    src/drive.py \
    src/encoder_test.py \
    src/heading.py \
    src/parking_final.py \
    src/servo_test.py
```

A syntax check proves only that Python can parse the files.

It does not prove:

- camera access;
- I2C communication;
- GPIO operation;
- correct steering;
- correct motor direction;
- correct vision thresholds;
- successful autonomous behaviour.

Physical testing remains required.

---

# 23. Verify Core Local Modules

Enter the source directory:

```bash
cd src
```

Check modules that can safely be imported in the current environment:

```bash
python3 - <<'PY'
import drive
import heading
import openvision
import N_Vision_final

print("drive.py: OK")
print("heading.py: OK")
print("openvision.py: OK")
print("N_Vision_final.py: OK")
print("Core source imports: PASS")
PY
```

Return to the repository root:

```bash
cd ..
```

> [!NOTE]
> Some hardware modules may initialize GPIO, cameras or I2C devices at import time.
>
> If a module intentionally performs hardware setup during import, test it only with the robot safely connected and powered.

---

# 24. Verify `heading.py`

Place the robot on a stable surface.

The MPU6050 must remain still during calibration.

Run:

```bash
python3 src/heading.py
```

Confirm:

- initialization succeeds;
- no I2C exception occurs;
- stationary calibration completes;
- heading values can be obtained;
- the documented left/right heading convention matches physical movement.

The result is a **relative heading estimate**, not a drift-free global compass.

---

# 25. Verify Motor Direction Safely

Before this test:

- raise the drive wheels;
- confirm the area is clear;
- secure the battery;
- keep a power disconnect available.

From the repository root:

```bash
cd src
python3
```

Then:

```python
import drive
```

Test low-speed forward motion using the current function signature defined by `drive.py`.

For example, if the current source accepts a speed argument:

```python
drive.forward(20)
```

Stop:

```python
drive.stop()
```

Test reverse:

```python
drive.backward(20)
```

Stop:

```python
drive.stop()
```

If `drive.py` exposes a cleanup function:

```python
drive.cleanup()
```

Exit:

```python
exit()
```

Confirm:

- forward direction is physically correct;
- reverse direction is correct;
- the motor stops correctly;
- no mechanical binding occurs;
- gears remain engaged.

---

# 26. Verify Steering Safely

The preferred steering test is:

```bash
python3 src/servo_test.py
```

Alternatively, if testing interactively:

```bash
cd src
python3
```

Then:

```python
import drive
drive.steer(drive.CENTER)
drive.steer(drive.LEFT)
drive.steer(drive.CENTER)
drive.steer(drive.RIGHT)
drive.steer(drive.CENTER)
```

If available:

```python
drive.cleanup()
```

Exit:

```python
exit()
```

Confirm:

- steering direction is correct;
- centre is suitable for straight travel;
- linkage does not bind;
- servo does not force the mechanism past safe travel;
- steering commands remain inside the calibrated mechanical range.

---

# 27. Open Challenge Vision

The current Open Challenge vision module is:

```text
src/openvision.py
```

The current Open Challenge controller is:

```text
src/Sentio_Open_2026.py
```

The Open vision system is responsible for the visual information required by the Open Challenge, including wall and course-marker observations used by the controller.

The physically tested source remains authoritative for:

- resolution;
- FPS;
- ROI coordinates;
- colour thresholds;
- contour filters;
- proportional gain;
- line cooldown;
- speed and acceleration settings.

Do not copy tuning constants from an older version simply because the filename looks similar.

---

# 28. Obstacle Vision

The current multi-ROI vision module is:

```text
src/N_Vision_final.py
```

It supports observations involving:

```text
RED
GREEN
BLACK
BLUE
ORANGE
MAGENTA
```

as required by the current challenge architecture.

The system may combine:

- HSV information;
- LAB information;
- contour geometry;
- contour area;
- ROI identity;
- morphological filtering;
- body-exclusion regions.

The current documentation uses a multi-ROI image architecture approximately based on:

```text
720 × 360
```

The exact active camera configuration and threshold values should be read from the current tested source.

---

# 29. Field Colour Calibration

The current calibration utility is:

```text
src/Cal_APOC.py
```

Run:

```bash
python3 src/Cal_APOC.py
```

Calibration should be performed with:

- final camera mount;
- competition-like field lighting;
- final exposure behaviour;
- representative target colours;
- robot placed at useful near and far distances.

Check:

- black;
- blue;
- orange;
- red;
- green;
- magenta;
- any LAB / HSV ranges used by the final vision source.

After calibration, synchronize the resulting values with the competition vision files if required by the current workflow.

Do not recalibrate one file while accidentally leaving the challenge controller dependent on another stale vision file.

---

# 30. Run the Open Challenge

From the repository root:

```bash
cd ~/World-Robot-Olympiad---Team-Sentio-
```

Run:

```bash
python3 src/Sentio_Open_2026.py
```

Before a complete run:

1. verify camera mapping;
2. verify steering centre;
3. verify motor direction;
4. verify black-wall detection;
5. verify blue/orange course-marker detection;
6. confirm the correct calibration;
7. place the robot correctly;
8. clear the track;
9. confirm the exact Git revision being tested.

The final source itself remains authoritative for:

- acceleration;
- speed;
- steering gain;
- course-event count;
- cooldown;
- final stopping behaviour.

---

# 31. Run the Obstacle Challenge

From the repository root:

```bash
python3 src/Final_Obstacle_Challenge.py
```

The current architecture uses supporting modules including:

```text
N_Vision_final.py
heading.py
drive.py
parking_final.py
TOF_22.py
```

depending on the exact final integration.

The Obstacle Challenge combines:

- black-wall observations;
- red-pillar observations;
- green-pillar observations;
- direction-aware navigation;
- course-event counting;
- MPU6050 relative heading;
- encoder-assisted movement;
- parking transition logic.

Before running:

1. confirm MPU6050 communication;
2. allow IMU calibration to complete while stationary;
3. verify camera detection;
4. verify steering;
5. verify motor direction;
6. verify the encoder;
7. verify ToF sensors required by the parking stage;
8. verify parking dependencies;
9. position the robot correctly on the track.

---

# 32. Parking Architecture

The current parking controller is:

```text
src/parking_final.py
```

The parking architecture combines:

- camera geometry;
- wall observations;
- magenta parking references;
- MPU6050 heading;
- three VL53L0X sensors;
- encoder / drive control;
- forward and reverse Ackermann arcs.

Because Starlight uses Ackermann steering, it cannot rotate about its centre like a differential-drive robot.

Parking therefore requires controlled forward and reverse movement.

The final tested parking source is authoritative for:

- camera indices;
- ToF mapping;
- distance thresholds;
- heading thresholds;
- encoder movement;
- parking entry sequence;
- final stop logic.

---

# 33. Clockwise and Anticlockwise Parking

Clockwise and anticlockwise course completion do not place the robot in identical positions.

The parking architecture therefore contains direction-dependent positioning before final alignment.

Conceptually:

```text
CLOCKWISE
Course complete
      ↓
Direction-specific entry
      ↓
Parking positioning
      ↓
Final parallel alignment
      ↓
STOP
```

```text
ANTICLOCKWISE
Course complete
      ↓
Required reposition / turn
      ↓
Wall-relative approach
      ↓
Parking positioning
      ↓
Final parallel alignment
      ↓
STOP
```

The exact final sequence must match the physically tested `parking_final.py` and Obstacle Challenge integration.

---

# 34. Verify ToF Behaviour Before Parking

Run:

```bash
python3 src/TUF_test.py
```

Confirm all three sensors.

Then check the ToF module:

```text
src/TOF_22.py
```

against the physical sensor arrangement.

For each sensor, document:

- XSHUT GPIO;
- working I2C address;
- physical position;
- viewing direction;
- software variable name;
- parking condition that uses it.

A correct number from the wrong physical sensor is still wrong.

---

# 35. Component-Test Programs

The repository includes dedicated tests:

| Subsystem | File |
|---|---|
| Steering | `src/servo_test.py` |
| Encoder / drive movement | `src/encoder_test.py` |
| ToF sensors | `src/TUF_test.py` |
| Heading | `src/heading.py` |
| Vision calibration | `src/Cal_APOC.py` |

Recommended order:

```text
Power / wiring
      ↓
Individual component
      ↓
Subsystem
      ↓
Low-speed integration
      ↓
Full challenge
```

Do not begin debugging a complete autonomous run when the actual fault can be reproduced with a small component test.

---

# 36. Recommended Testing Sequence

Use:

```text
Power / wiring check
        ↓
GPIO import
        ↓
I2C detection
        ↓
MPU6050 calibration
        ↓
Camera 0 test
        ↓
Camera 1 test
        ↓
Steering test
        ↓
Motor direction test
        ↓
Encoder test
        ↓
Three-ToF test
        ↓
Field colour calibration
        ↓
Open vision check
        ↓
Obstacle vision check
        ↓
Low-speed Open Challenge
        ↓
Full Open Challenge
        ↓
Low-speed Obstacle Challenge
        ↓
Full Obstacle Challenge
        ↓
Parking validation
```

This allows faults to be isolated before several subsystems interact.

---

# 37. Minimum Pre-Run Verification

## Power

- battery connected correctly;
- battery secure;
- Raspberry Pi supply stable;
- no repeated undervoltage warning;
- common electrical reference present.

## Mechanical

- wheels rotate freely;
- gears remain engaged;
- motor mount secure;
- steering linkage intact;
- steering does not bind;
- camera mounts rigid;
- ToF mounts rigid.

## Raspberry Pi

```bash
python3 --version
```

```bash
python3 -c "import cv2, numpy, smbus2; print('Python dependencies OK')"
```

```bash
python3 -c "import RPi.GPIO as GPIO; print('GPIO OK')"
```

## IMU

```bash
i2cdetect -y 1
```

Confirm the MPU6050 appears at:

```text
0x68
```

## Cameras

```bash
rpicam-hello --list-cameras
```

Confirm both cameras are present.

## Source

```bash
git status
```

```bash
git rev-parse HEAD
```

Confirm the physically tested source is the source being run.

---

# 38. Repository Integrity Check

The GitHub repository should contain every module required by the competition controllers.

At minimum, verify:

```text
src/Cal_APOC.py
src/Final_Obstacle_Challenge.py
src/N_Vision_final.py
src/Sentio_Open_2026.py
src/openvision.py
src/TOF_22.py
src/TUF_test.py
src/drive.py
src/encoder_test.py
src/heading.py
src/parking_final.py
src/servo_test.py
```

There should not be a required module that exists only on the working Raspberry Pi.

The intended relationship is:

```text
Physical robot configuration
        =
Raspberry Pi source
        =
GitHub source
        =
Documentation
```

If a final competition source imports a differently named helper, add that exact tested helper or synchronize the source before freezing the repository.

Do not "fix" an import by guessing which historical file it was probably supposed to use.

---

# 39. Clean-Clone Verification

After cloning the repository on a clean Raspberry Pi environment:

```bash
git status
```

should show a clean working tree before local calibration changes are made.

Syntax-check the source:

```bash
python3 -m py_compile \
    src/Cal_APOC.py \
    src/Final_Obstacle_Challenge.py \
    src/N_Vision_final.py \
    src/Sentio_Open_2026.py \
    src/openvision.py \
    src/TOF_22.py \
    src/TUF_test.py \
    src/drive.py \
    src/encoder_test.py \
    src/heading.py \
    src/parking_final.py \
    src/servo_test.py
```

Then perform hardware tests in the order documented above.

A clean clone is not considered validated merely because all files compile.

---

# 40. Troubleshooting — GPIO Import Failure

If:

```bash
python3 -c "import RPi.GPIO as GPIO"
```

fails, install the Raspberry Pi 5 compatibility package:

```bash
sudo apt install -y python3-rpi-lgpio
```

If necessary:

```bash
sudo apt remove -y python3-rpi.gpio
sudo apt install -y python3-rpi-lgpio
```

Then test again.

---

# 41. Troubleshooting — PWM Object Already Exists

If execution reports something similar to:

```text
RuntimeError: A PWM object already exists for this GPIO channel
```

check whether two different drive modules are being imported in the same Python process.

For example, avoid an architecture in which one stage initializes:

```python
import drive
```

and a later stage imports another module that creates a second PWM object on the same motor or servo GPIO.

Also check whether another robot process is still running:

```bash
ps aux | grep python
```

Stop only the known conflicting process:

```bash
kill <PID>
```

If required:

```bash
sudo kill <PID>
```

The preferred competition architecture should have one clear owner for each GPIO PWM resource.

Do not attempt to solve a duplicate-PWM error by adding arbitrary sleeps. Time is many things, but it is not garbage collection.

---

# 42. Troubleshooting — MPU6050 Not Detected

Run:

```bash
i2cdetect -y 1
```

If `68` is absent:

- power off;
- inspect VCC;
- inspect GND;
- inspect SDA;
- inspect SCL;
- reseat connectors;
- reboot;
- repeat the scan.

Do not begin the Obstacle Challenge while the sensor connection is unresolved.

---

# 43. Troubleshooting — ToF Sensor Failure

If one or more VL53L0X sensors fail to initialize:

1. power-cycle the robot;
2. inspect all three XSHUT connections;
3. inspect SDA and SCL;
4. confirm common ground;
5. verify the correct XSHUT GPIO numbers;
6. run `src/TUF_test.py`;
7. verify sensors are enabled sequentially;
8. check that unique working addresses are assigned;
9. confirm a sensor is not physically disconnected or swapped.

Because identical VL53L0X sensors begin at the same default address, attempting to communicate with all of them before address assignment can create an I2C conflict.

---

# 44. Troubleshooting — Camera Not Detected

Run:

```bash
rpicam-hello --list-cameras
```

If one camera is missing:

1. power off the Raspberry Pi;
2. reseat the CSI ribbon;
3. inspect ribbon orientation;
4. inspect connector locks;
5. reboot;
6. test again.

Do not reconnect CSI cables while the Raspberry Pi is powered.

---

# 45. Troubleshooting — Wrong Camera Used

If a controller displays the wrong physical camera:

```bash
rpicam-hello --list-cameras
```

Verify which physical camera corresponds to each index.

Do not modify software camera indices until the actual hardware enumeration is known.

Any camera-index change should be followed by complete vision and parking retesting.

---

# 46. Troubleshooting — Motor Does Not Move

Check:

- battery;
- motor-driver power;
- common ground;
- GPIO5;
- GPIO6;
- GPIO13;
- TB6612FNG wiring;
- drivetrain freedom;
- motor connections.

Test at reduced speed with the wheels raised.

A non-moving motor is not automatically a software failure.

---

# 47. Troubleshooting — Motor Direction Reversed

If the software's forward command causes physical reverse motion:

1. compare wiring with the schematic;
2. compare the installed `drive.py` with the tested competition version;
3. confirm IN1 / IN2 connections;
4. confirm motor polarity;
5. determine whether the difference is hardware or software before changing either.

The goal is to reproduce the physically validated robot, not create a new convention five minutes before a run.

---

# 48. Troubleshooting — Steering Direction Incorrect

Check:

- GPIO22;
- servo supply;
- common ground;
- linkage orientation;
- servo horn installation;
- current `drive.py`;
- current `servo_test.py`.

Do not expand steering range as a first troubleshooting step.

---

# 49. Troubleshooting — Steering Oscillation

Possible causes include:

- proportional gain too large;
- noisy wall target;
- camera movement;
- unstable lighting;
- loose linkage;
- excessive mechanical steering travel;
- vision-threshold instability.

Change one variable at a time and retest.

---

# 50. Troubleshooting — Poor Colour Detection

Before changing thresholds:

1. clean the camera lens;
2. verify camera angle;
3. verify illumination;
4. confirm the correct camera;
5. inspect the debug image if enabled;
6. inspect contour size;
7. confirm target colour;
8. compare with competition-like lighting;
9. run `Cal_APOC.py`.

Do not assume Open Challenge and Obstacle Challenge thresholds are interchangeable.

The relevant current modules are:

```text
openvision.py
N_Vision_final.py
```

Each should retain the values validated for its actual use.

---

# 51. Troubleshooting — Encoder Does Not Count

Run:

```bash
python3 src/encoder_test.py
```

Check:

- GPIO17;
- GPIO27;
- encoder power;
- encoder ground;
- signal wiring;
- motor movement;
- count direction;
- mechanical encoder connection.

If the motor moves but the count does not change, stop encoder-targeted movements until the feedback path is repaired.

---

# 52. Troubleshooting — Import Failure

If a competition controller reports:

```text
ModuleNotFoundError
```

do not immediately create a dummy replacement module.

Check:

```bash
grep -R "^import\|^from" src/*.py
```

Then compare the imports against:

```bash
ls src
```

Every required local module should either:

- exist in the repository; or
- be a documented external dependency.

Synchronize from the physically tested Raspberry Pi if GitHub is missing a required helper.

---

# 53. Troubleshooting — Parking Function Error

If the Obstacle Challenge reports an error such as:

```text
AttributeError:
module 'parking_final' has no attribute '...'
```

compare:

```text
Final_Obstacle_Challenge.py
parking_final.py
```

with the working Raspberry Pi versions.

The function called by the controller and the function defined by the parking module must match.

Do not rename functions without rerunning the complete Obstacle + Parking sequence.

---

# 54. Do Not Tune Multiple Variables at Once

Avoid simultaneously changing:

- motor speed;
- steering centre;
- steering limits;
- proportional gain;
- colour thresholds;
- ROI coordinates;
- camera position;
- obstacle area threshold;
- orange / blue marker cooldown;
- ToF distance threshold;
- encoder target;
- heading threshold;
- parking timing.

Instead:

```text
Change one variable
      ↓
Test
      ↓
Record result
      ↓
Keep or revert
      ↓
Move to next variable
```

This makes cause-and-effect much easier to identify.

---

# 55. Competition Calibration Policy

Values such as:

```text
Steering center
Steering limits
Motor speed
Proportional gain
Colour thresholds
ROI coordinates
Course-marker cooldown
Distance thresholds
Encoder movement targets
Parking timing
Heading thresholds
```

can change during field calibration.

The final physically tested source is authoritative.

Whenever competition calibration changes:

1. update the Raspberry Pi source;
2. test the affected subsystem;
3. test the affected challenge;
4. commit the tested source;
5. push the tested revision;
6. update documentation if architecture or interfaces changed.

---

# 56. Final Competition Release Check

Before freezing the repository:

- [ ] Raspberry Pi boots correctly.
- [ ] No repeated undervoltage warning.
- [ ] GPIO interface imports.
- [ ] I2C is enabled.
- [ ] MPU6050 detected at `0x68`.
- [ ] `heading.py` calibration succeeds.
- [ ] Front / primary navigation camera detected.
- [ ] Second camera detected.
- [ ] Camera indices match the tested source.
- [ ] Camera mounts secure.
- [ ] Motor direction correct.
- [ ] Drivetrain mechanically free.
- [ ] Encoder responds correctly.
- [ ] `encoder_test.py` passes.
- [ ] Steering linkage secure.
- [ ] Steering range mechanically safe.
- [ ] `servo_test.py` passes.
- [ ] All three VL53L0X sensors initialize.
- [ ] XSHUT sequencing works.
- [ ] `TOF_22.py` matches the tested sensor arrangement.
- [ ] `TUF_test.py` passes.
- [ ] `Cal_APOC.py` calibration matches competition lighting.
- [ ] `openvision.py` works.
- [ ] `N_Vision_final.py` works.
- [ ] Open Challenge source matches the physically tested file.
- [ ] Obstacle Challenge source matches the physically tested file.
- [ ] Parking source matches the physically tested file.
- [ ] Open Challenge completes a physical run.
- [ ] Obstacle Challenge completes a physical run.
- [ ] Parking completes physically.
- [ ] No required helper exists only on the Raspberry Pi.
- [ ] `git status` shows no accidental local source changes.
- [ ] Final Git commit SHA is recorded.
- [ ] GitHub matches the working Raspberry Pi.

---

# 57. Final Reproduction Sequence

A clean reproduction should follow:

```text
Install Raspberry Pi OS
        ↓
Update system
        ↓
Install dependencies
        ↓
Configure GPIO support
        ↓
Enable I2C
        ↓
Verify MPU6050
        ↓
Connect and verify both cameras
        ↓
Clone repository
        ↓
Record Git revision
        ↓
Syntax-check source
        ↓
Verify external Python imports
        ↓
Verify drive + steering
        ↓
Verify encoder
        ↓
Verify all three ToF sensors
        ↓
Calibrate vision
        ↓
Test Open vision
        ↓
Test Obstacle vision
        ↓
Run Open Challenge
        ↓
Run Obstacle Challenge
        ↓
Validate parking
        ↓
Confirm GitHub and Raspberry Pi are synchronized
```

---

# 58. Repository Reproduction Resources

Use the repository material together.

| Resource | Location |
|---|---|
| Project overview | [`../README.md`](../README.md) |
| Development history | [`../CHANGELOG.md`](../CHANGELOG.md) |
| Software requirements | [`../requirements.md`](../requirements.md) |
| Software dependencies | [`Software_Dependencies.md`](Software_Dependencies.md) |
| Bill of materials | [`BOM_purchase_links.md`](BOM_purchase_links.md) |
| Wiring guide | [`wiring_guide.md`](wiring_guide.md) |
| Open Challenge | [`../src/Sentio_Open_2026.py`](../src/Sentio_Open_2026.py) |
| Open Challenge vision | [`../src/openvision.py`](../src/openvision.py) |
| Obstacle Challenge | [`../src/Final_Obstacle_Challenge.py`](../src/Final_Obstacle_Challenge.py) |
| Multi-ROI vision | [`../src/N_Vision_final.py`](../src/N_Vision_final.py) |
| Drive control | [`../src/drive.py`](../src/drive.py) |
| Encoder test | [`../src/encoder_test.py`](../src/encoder_test.py) |
| MPU6050 heading | [`../src/heading.py`](../src/heading.py) |
| Parking | [`../src/parking_final.py`](../src/parking_final.py) |
| Three-ToF interface | [`../src/TOF_22.py`](../src/TOF_22.py) |
| ToF test | [`../src/TUF_test.py`](../src/TUF_test.py) |
| Field calibration | [`../src/Cal_APOC.py`](../src/Cal_APOC.py) |
| Steering test | [`../src/servo_test.py`](../src/servo_test.py) |
| Electrical schematic | [`../schemes/`](../schemes/) |
| CAD / printable components | [`../Models/`](../Models/) |
| Vehicle photographs | [`../v-photos/`](../v-photos/) |
| Team photographs | [`../t-photos/`](../t-photos/) |
| Autonomous video evidence | [`../videos/`](../videos/) |
| Supporting engineering material | [`../other/`](../other/) |

---

# 59. Final Release Principle

The repository should satisfy:

```text
Physical Starlight
        =
Software on Raspberry Pi
        =
Software on GitHub
        =
Reproduction documentation
```

If a final competition adjustment changes:

- steering calibration;
- motor speed;
- proportional gain;
- colour threshold;
- ROI geometry;
- obstacle threshold;
- camera mapping;
- marker timing;
- ToF logic;
- encoder movement;
- parking logic;
- heading logic;

the updated version must be retested before it is treated as the final validated competition source.

The goal is not merely for one Raspberry Pi to run successfully.

The goal is for the repository to accurately represent the robot that was physically tested.

---

**Team Sentio 6010**  
**Starlight**  
**World Robot Olympiad — Future Engineers 2026**  
**Robofun Lab (RFL), India**

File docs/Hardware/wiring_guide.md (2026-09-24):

# Starlight Wiring & Pin Reference

**Project:** Starlight  
**Team:** Sentio 6010 
**Competition:** WRO Future Engineers 2026  
**Configuration:** APOC / Revision 29  
**Last updated:** 22 September 2026

This document is a quick reference for Starlight's **power architecture, physical wiring, sensor interfaces and software GPIO assignments**.

> [!IMPORTANT]
> The [final schematic](../../schemes/schematic.png) is the authority for physical wiring.
>
> Source-code pin definitions are authoritative for software GPIO assignments. If this document, the schematic and the robot disagree, the discrepancy must be resolved before competition.

---

# Power Architecture

The current robot uses one 3S LiPo battery with separate propulsion and regulated electronics branches.

```text
                         3S LiPo
                   11.1 V nominal
                         │
                  Main power switch
                         │
        ┌────────────────┴─────────────────┐
        │                                  │
        │                                  │
        ▼                                  ▼
   MOTOR BRANCH                     REGULATED BRANCHES
        │                                  │
        ▼                         ┌────────┴────────┐
   TB6612FNG VMOT                 │                 │
        │                         ▼                 ▼
        ▼                    5 V / ~5 A        5 V / 3 A
600 RPM encoder motor         Pi supply       auxiliary rail
                                  │                 │
                                  ▼                 ├── Steering servo
                            Raspberry Pi 5          │
                                  │                 └── other 5 V loads
                 ┌────────────────┼───────────────┐
                 │                │               │
                 ▼                ▼               ▼
              Camera 0         Camera 1        I2C bus
                                                   │
                              ┌────────────────────┼─────────────────┐
                              │                    │                 │
                              ▼                    ▼                 ▼
                           MPU6050             VL53L0X #1       VL53L0X #2
                                                                     │
                                                                     ▼
                                                                VL53L0X #3
```

All control electronics share a **common electrical reference / ground**.

The propulsion branch and regulated electronics branches serve different loads even though they share the same battery.

---

# Current Hardware Relevant to Wiring

| Qty. | Component | Electrical role |
| ---: | --- | --- |
| 1 | Raspberry Pi 5, 4 GB | Main controller |
| 2 | Raspberry Pi Camera Module 3 Wide | Vision inputs |
| 3 | VL53L0X ToF sensors | Short-range distance sensing |
| 1 | MPU6050-based module | Heading / gyro input |
| 1 | 12 V, 600 RPM geared encoder motor | Propulsion |
| 1 | Integrated quadrature encoder | Shaft rotation and direction |
| 1 | TB6612FNG motor driver | Motor PWM and direction |
| 1 | DS3225 servo | Ackermann steering |
| 1 | 3S LiPo, 11.1 V, 2200 mAh | Main energy source |
| 1 | Regulated 5 V Pi supply, approximately 5 A | Raspberry Pi rail |
| 1 | 5 V / 3 A buck converter / BEC | Auxiliary regulated rail |
| 1 | Main power switch | Vehicle power isolation |
| 1 | Momentary Start button | Autonomous-run start input |

---

# Software GPIO Reference

These values follow the current robot source and Revision 27 wiring baseline.

| Function | BCM GPIO / Interface | Source / role |
| --- | ---: | --- |
| **Motor PWM** | **GPIO13** | `src/drive.py` |
| **Motor direction 1** | **GPIO5** | `src/drive.py` |
| **Motor direction 2** | **GPIO6** | `src/drive.py` |
| **Steering servo** | **GPIO22** | `src/drive.py` |
| **Encoder channel A** | **GPIO17** | `src/drive.py` |
| **Encoder channel B** | **GPIO27** | `src/drive.py` |
| **I2C SDA** | **GPIO2** | Shared sensor bus |
| **I2C SCL** | **GPIO3** | Shared sensor bus |
| **MPU6050 bus** | **I2C bus 1** | `src/heading.py` |
| **MPU6050 address** | **`0x68`** | `src/heading.py` |
| **ToF 1 XSHUT** | **GPIO16** | Distance-sensor initialization |
| **ToF 2 XSHUT** | **GPIO20** | Distance-sensor initialization |
| **ToF 3 XSHUT** | **GPIO21** | Distance-sensor initialization |

---

# Motor Driver Interface

The current drive interface uses:

```text
PWM_PIN   = GPIO13
IN1_PIN   = GPIO5
IN2_PIN   = GPIO6
```

Motor PWM frequency:

```text
1000 Hz
```

Conceptually:

```text
Raspberry Pi
     │
     ├── GPIO13 ──► PWM
     ├── GPIO5  ──► IN1
     └── GPIO6  ──► IN2
                       │
                       ▼
                  TB6612FNG
                       │
                       ▼
              600 RPM drive motor
```

The motor receives propulsion power through the motor-driver battery branch.

---

# Current Drive Motor

The current competition motor is:

```text
12 V geared DC motor
Nominal output speed: 600 RPM
Integrated quadrature encoder
```

The external drivetrain ratio is:

```text
1 : 1
```

The earlier:

```text
1000 RPM motor
36T → 24T
1.5 speed-increasing ratio
```

belongs to historical development documentation and must not be used as the current wiring/configuration reference.

---

# Encoder Wiring

The current drive motor includes an integrated quadrature encoder.

Software uses:

```text
ENCODER_A_PIN = GPIO17
ENCODER_B_PIN = GPIO27
```

Conceptually:

```text
ENCODER
   │
   ├── Channel A ──► GPIO17
   ├── Channel B ──► GPIO27
   ├── Supply
   └── Ground
```

The two channels allow the controller to observe:

```text
shaft rotation
+
rotation direction
```

---

## Encoder Electrical Warning

> [!CAUTION]
> Do not assume the encoder's output voltage is Raspberry Pi-safe simply because its encoder electronics use a particular supply voltage.

Before direct GPIO connection:

1. verify the installed encoder's output-high voltage;
2. verify common ground;
3. use level shifting or signal conditioning if required;
4. keep encoder signal wiring away from motor-current wiring where practical.

Brushed motor noise can otherwise produce false counts.

The software-level encoder test is:

```text
src/encoder_test.py
```

---

# Steering Wiring

The steering servo signal is connected to:

```text
GPIO22
```

Servo PWM frequency:

```text
50 Hz
```

Conceptually:

```text
Raspberry Pi GPIO22
        │
        ▼
   Servo signal

Regulated 5 V rail
        │
        ▼
    Servo VCC

Common ground
        │
        ▼
    Servo GND
```

The servo should **not** be powered directly from an unsuitable Raspberry Pi GPIO power path.

---

# Current Steering Values

The current `src/drive.py` defines:

```text
LEFT   = 40
CENTER = 75
RIGHT  = 110
```

These values are **servo command values**.

They are not measured road-wheel steering angles.

Do not silently replace them with older values such as:

```text
35 / 75 / 105
```

unless the physically tested final source has actually been recalibrated.

---

# I2C Bus

The main I2C bus uses:

```text
SDA = GPIO2
SCL = GPIO3
```

Connected sensor systems include:

```text
MPU6050
VL53L0X #1
VL53L0X #2
VL53L0X #3
```

Conceptually:

```text
Raspberry Pi
   │
   ├── GPIO2 / SDA ──────────────────────────────┐
   │                                             │
   └── GPIO3 / SCL ──────────────────────────────┤
                                                 │
                  ┌──────────────────────────────┼───────────────┐
                  │                              │               │
                  ▼                              ▼               ▼
              MPU6050                       VL53L0X #1      VL53L0X #2
                  │                                              │
                  │                                              ▼
                  └───────────────────────────────────────── VL53L0X #3
```

---

# MPU6050

The heading module uses:

```text
I2C bus : 1
Address : 0x68
```

Software:

```text
src/heading.py
```

The MPU6050 provides angular-rate information used to estimate relative heading.

It does not provide an absolute drift-free compass heading.

---

# Three VL53L0X Sensors

The current robot uses:

```text
3 × VL53L0X
```

All three sensors share:

```text
SDA
SCL
power
ground
```

but each requires an independent **XSHUT** control line.

| Sensor | XSHUT |
| --- | ---: |
| **ToF 1** | GPIO16 |
| **ToF 2** | GPIO20 |
| **ToF 3** | GPIO21 |

---

## Why XSHUT Is Required

Each VL53L0X begins at the same default I2C address.

If all three sensors became active simultaneously at that address, the Raspberry Pi could not reliably address them individually.

Startup therefore follows:

```text
All ToF sensors OFF
        ↓
Enable ToF 1
        ↓
Assign unique address
        ↓
Enable ToF 2
        ↓
Assign unique address
        ↓
Enable ToF 3
        ↓
Assign unique address
        ↓
Verify all three
```

The three independent XSHUT lines make this possible.

---

# ToF Wiring Concept

```text
                         Raspberry Pi 5
                               │
              ┌────────────────┴────────────────┐
              │                                 │
          GPIO2 SDA                         GPIO3 SCL
              │                                 │
        ┌─────┼─────────┐                 ┌─────┼─────────┐
        │     │         │                 │     │         │
        ▼     ▼         ▼                 ▼     ▼         ▼
      ToF1  ToF2      ToF3              ToF1  ToF2      ToF3

GPIO16 ─────────────────────────► ToF 1 XSHUT

GPIO20 ─────────────────────────► ToF 2 XSHUT

GPIO21 ─────────────────────────► ToF 3 XSHUT
```

All three sensors require a shared electrical reference.

The low-level sensor test is:

```text
src/TUF_test.py
```

---

# ToF Mounting Matters

The electrical connection alone does not determine what a distance reading means.

Each sensor must also be mounted so that its measurement direction corresponds to the intended:

- wall;
- parking boundary;
- nearby obstacle;
- stopping reference.

Therefore:

```text
sensor identity
+
GPIO identity
+
software identity
+
physical direction
```

must remain consistent.

Label the ToF connectors physically.

---

# Cameras

Starlight uses:

```text
2 × Raspberry Pi Camera Module 3 Wide
```

The software uses separate camera interfaces for the two available camera channels.

The retained logical mapping is:

| Camera | Index | Primary role |
| --- | ---: | --- |
| **Camera 0** | `0` | Main navigation / challenge perception |
| **Camera 1** | `1` | Secondary / parking view where used |

> [!NOTE]
> Camera placement changed during the post-Nationals redesign.
>
> Camera numbering is a **software interface**, while "front", "rear" or "rear-mounted" describes physical placement. Do not assume those are interchangeable labels after rebuilding the robot.

Before competition:

```bash
rpicam-hello --list-cameras
```

should be used to confirm both cameras.

---

# Main Power Branch

The drive motor uses the battery propulsion branch through the TB6612FNG.

```text
3S LiPo
   │
   ▼
Main switch
   │
   ▼
TB6612FNG VMOT
   │
   ▼
600 RPM drive motor
```

Do not route raw 3S LiPo voltage into a device expecting a regulated 5 V or 3.3 V supply.

---

# Raspberry Pi Supply

The current BOM specifies a regulated Raspberry Pi supply of approximately:

```text
5 V / 5 A capacity
```

This is a **supply-capacity rating**, not a claim that the Raspberry Pi continuously draws 5 A.

Earlier development produced Raspberry Pi undervoltage warnings, so adequate transient current margin is part of the final power architecture.

---

# Auxiliary Regulated Rail

The BOM retains a:

```text
5 V / 3 A buck converter / BEC
```

as an auxiliary regulated supply where used.

Typical regulated loads include the steering / low-voltage actuation side according to the final schematic.

The physical schematic remains authoritative for the exact final distribution.

---

# Common Ground

Connected control systems must share a common electrical reference.

Conceptually:

```text
Battery ground
      │
      ├── Motor driver ground
      ├── Raspberry Pi supply ground
      ├── Auxiliary regulator ground
      ├── Servo ground
      ├── MPU6050 ground
      ├── ToF grounds
      └── Encoder ground
```

Without a valid common reference, logic signals may not be interpreted correctly.

---

# Important Electrical Notes

- The **600 RPM motor** uses the propulsion branch through the TB6612FNG.
- The Raspberry Pi uses its regulated **5 V / approximately 5 A** supply.
- The auxiliary **5 V / 3 A** regulator is retained where required.
- The current robot uses **three VL53L0X sensors**, not two.
- The ToF XSHUT pins are **GPIO16, GPIO20 and GPIO21**.
- The encoder channels used by the current drive source are **GPIO17 and GPIO27**.
- The MPU6050 uses **I2C bus 1** at **`0x68`**.
- All connected control branches require an appropriate common electrical reference.
- Raw 3S battery voltage must not be connected directly to 5 V or 3.3 V inputs.
- Motor wiring should be kept away from low-level encoder and sensor wiring where practical.
- Connector and cable strain relief is part of the electrical design.
- Exact physical routing should follow the final schematic rather than an old robot photograph.

---

# Current Pin Summary

```text
MOTOR
GPIO13  → Motor PWM
GPIO5   → Motor direction IN1
GPIO6   → Motor direction IN2

STEERING
GPIO22  → Steering servo signal

ENCODER
GPIO17  → Encoder channel A
GPIO27  → Encoder channel B

I2C
GPIO2   → SDA
GPIO3   → SCL

MPU6050
Bus 1
Address 0x68

TOF XSHUT
GPIO16  → ToF 1
GPIO20  → ToF 2
GPIO21  → ToF 3
```

---

# Wiring Verification Checklist

Before a competition run:

- [ ] Battery polarity verified
- [ ] Main switch works
- [ ] Motor-driver battery branch secure
- [ ] Raspberry Pi regulated supply is 5 V
- [ ] Auxiliary regulated supply is 5 V where used
- [ ] Common ground verified
- [ ] GPIO5 and GPIO6 motor direction wiring verified
- [ ] GPIO13 motor PWM verified
- [ ] GPIO22 steering signal verified
- [ ] GPIO17 encoder channel A verified
- [ ] GPIO27 encoder channel B verified
- [ ] Encoder signal voltage confirmed safe
- [ ] GPIO2 SDA verified
- [ ] GPIO3 SCL verified
- [ ] MPU6050 responds at `0x68`
- [ ] ToF 1 XSHUT verified on GPIO16
- [ ] ToF 2 XSHUT verified on GPIO20
- [ ] ToF 3 XSHUT verified on GPIO21
- [ ] All three ToF sensors initialize from cold boot
- [ ] ToF sensors receive separate working addresses
- [ ] ToF physical labels match software identities
- [ ] Both cameras detected
- [ ] Camera ribbon cables strain-relieved
- [ ] No wire can enter the drivetrain
- [ ] No wire can enter the steering mechanism
- [ ] No exposed conductor can contact the chassis or adjacent terminal
- [ ] Motor acceleration does not reset the Raspberry Pi
- [ ] Servo movement does not produce an undervoltage warning

---

# Recorded Voltage Measurements

The following values were recorded during electrical testing:

| Measurement point | Condition | Recorded value |
| --- | --- | ---: |
| LiPo | Before run | **11.1 V** |
| LiPo | After multiple runs | **10.8 V** |
| Motor driver | Motor OFF | **11.1 V** |
| Motor driver | Motor ON | **10.8 V** |
| Auxiliary / Buck 1 | Tested output | **5.0 V** |
| Raspberry Pi supply | Tested output | **5.0 V** |

> [!NOTE]
> These measurements are retained as recorded observations.
>
> They should not automatically be treated as a full electrical characterization of the current Revision 27 system unless they were measured after the final **600 RPM motor + three-ToF** configuration was assembled.

No final peak-current trace is claimed here unless separately recorded.

---

# Full-Load Power Check

The final electrical configuration should be tested with:

```text
Raspberry Pi running
+
both cameras active
+
MPU6050 active
+
three ToF sensors ranging
+
encoder active
+
servo moving
+
drive motor accelerating
```

Monitor for:

```text
Pi undervoltage
unexpected reboot
camera disconnect
I2C failure
encoder corruption
servo reset
motor-driver overheating
```

A system that measures 5.0 V while sitting motionless has not yet demonstrated that it can hold that rail during a real run. Electricity remains inconveniently interested in load.

---

# Historical Wiring Notes

The following items may still appear in older documentation or commits:

| Historical reference | Current status |
| --- | --- |
| JGB37-520 motor | Superseded |
| 1000 RPM Rhino motor | Historical supplier / development reference |
| Two ToF sensors | Superseded by **three ToF sensors** |
| 36T → 24T current gearing | Historical; current external ratio is **1:1** |
| Steering `35 / 75 / 105` | Older calibration |
| OLED as permanent payload | Development equipment / not required by current architecture |

Historical information should remain traceable, but it must not be presented as the current competition wiring configuration.

---

# Related Documentation

| Document | Purpose |
| --- | --- |
| [`bom.md`](bom.md) | Current hardware inventory |
| [`drivetrain.md`](drivetrain.md) | Motor, gearing, differential and encoder architecture |
| [`../engineering-decisions.md`](../engineering-decisions.md) | Why major hardware choices were made |
| [`../failure-log.md`](../failure-log.md) | Electrical and mechanical failures that drove changes |
| [`../testing.md`](../testing.md) | Hardware and integrated testing |
| [`../development/apoc-hardware-update.md`](../development/apoc-hardware-update.md) | Post-Nationals hardware redesign |
| [`../../schemes/schematic.png`](../../schemes/schematic.png) | Authoritative physical wiring schematic |
| [`../../src/drive.py`](../../src/drive.py) | Motor, servo and encoder GPIO definitions |
| [`../../src/heading.py`](../../src/heading.py) | MPU6050 interface |
| [`../../src/TUF_test.py`](../../src/TUF_test.py) | Three-sensor distance test |
| [`../../src/encoder_test.py`](../../src/encoder_test.py) | Encoder verification |
| [`../../src/servo_test.py`](../../src/servo_test.py) | Steering verification |

---

## Configuration Rule

The four references below should describe the same robot:

```text
Physical wiring
      =
schematic
      =
source-code GPIO assignments
      =
documentation
```

Any mismatch should be corrected before the configuration is frozen.

---

**Team Sentio 6010**  
**Starlight | WRO Future Engineers 2026**

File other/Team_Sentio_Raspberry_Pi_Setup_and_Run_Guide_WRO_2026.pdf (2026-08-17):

# Team Sentio

# Raspberry Pi Setup and Run Guide

### WRO Future Engineers 2026

Mechanical platform: V3
Open software: V5
Team Sentio | Robofun Lab (RFL), India

Purpose. This guide explains how to prepare a Raspberry Pi 5, verify the robot hardware, and run the Team Sentio Open Challenge program. It also records the current public-code status of the Obstacle and Parking programs so that the engineering journal does not claim more reproducibility than the repository currently provides.

Prepared for inclusion in the Team Sentio engineering documentation

## Contents

Team Sentio Raspberry Pi Setup and Run Guide | Team Sentio

## 1 Scope and safety

The competition vehicle uses a Raspberry Pi 5 (4 GB) running Raspberry Pi OS. The current Open Challenge program uses Picamera2, OpenCV, NumPy, and GPIO/PWM control. This document is intended for trained team members working with a real autonomous vehicle, a motor driver, a servo, and a 3S LiPo battery.

Hardware warning. The programs control real motors and steering. Keep the drivetrain lifted clear of the floor during the first hardware test, keep the emergency power switch accessible, and never connect the motor directly to a Raspberry Pi GPIO pin.

Do not continue testing if there is repeated Raspberry Pi rebooting, visible smoke, abnormal motor-driver heating, drivetrain binding, battery swelling, or uncertain battery polarity. LiPo charging must be supervised, with the correct cell-count setting and verified polarity.

## 2 Hardware connections

Connect the electronics according to the schematic in schemes/. Confirm a common ground between the Raspberry Pi, motor driver, servo supply, and sensor electronics before applying power. Check XT60 polarity before connecting the 3S LiPo. Connect the front Camera Module 3 used for navigation, the rear Camera Module 3 used for parking, the MPU6050, and the SSD1306 display.

BCM GPIO | Function | Connection / role
GPIO2 | I2C SDA | MPU6050 and SSD1306 data line
GPIO3 | I2C SCL | MPU6050 and SSD1306 clock line
GPIO5 | Motor direction 1 | TB6612FNG direction input 1
GPIO6 | Motor direction 2 | TB6612FNG direction input 2
GPIO13 | Motor PWM | TB6612FNG motor-speed PWM, 1 kHz
GPIO22 | Servo signal | DS3225 Ackermann steering servo, 50 Hz
GPIO18 | Push-button input | Auxiliary schematic connection; verify use in final software
GPIO23 / GPIO12 | Status LEDs | Auxiliary schematic connections; verify use in final software

The final challenge programs primarily use GPIO2/3, GPIO5/6/13, and GPIO22. Auxiliary GPIO assignments should remain in the guide only if the corresponding components are physically connected and used by the final software.

## 3 Install Raspberry Pi OS and dependencies

Use Raspberry Pi OS 64-bit on the Raspberry Pi 5. Raspberry Pi OS with Desktop is recommended for the present programs because they display diagnostic frames through cv2.imshow().
After the first boot, open a terminal and update the system:

sudo apt update

sudo apt full-upgrade -y

Install the core software packages:

sudo apt install -y git python3-venv python3-opencv python3-numpy \

python3-picamera2 i2c-tools

The code imports RPi.GPIO. Verify whether the GPIO interface is available:

python3 -c "import RPi.GPIO as GPIO; print('GPIO OK')"

On Raspberry Pi 5 systems where the original RPi.GPIO implementation is unavailable or incompatible, install the compatible implementation. Use one implementation or the other, not both in the same Python environment:

sudo apt install -y python3-rpi-lgpio

python3 -c "import RPi.GPIO as GPIO; print('GPIO OK')"

## 4 Enable I2C and verify the bus

Run the Raspberry Pi configuration utility:

sudo raspi-config

Open Interface Options → I2C → Enable, then reboot:

sudo reboot

After reboot, verify that the I2C bus responds:

i2cdetect -y 1

The connected MPU6050 and SSD1306 should appear on the bus before attempting any IMU-assisted parking or obstacle procedure.

## 5 Download the repository

Clone the repository and enter its root directory:

git clone https://github.com/teamsentiorobotics-svg/World-Robot-Olympiad---Team-

Sentio-.git

cd World-Robot-Olympiad---Team-Sentio-

The current challenge programs are stored at:

src/Open_Challenge.py

src/Obstacle_Challenge.py

If the team publishes a dependency file, install it from the repository root with:

python3 -m venv .venv

source .venv/bin/activate

pip install -r requirements.txt

The dependency file and setup commands must be tested on a clean Raspberry Pi before being described as the official final installation method.

## 6 Verify the cameras

List cameras detected by Raspberry Pi OS:

rpicam-hello --list-cameras

Both Camera Module 3 units should be detected before testing parking. The current public programs instantiate Picamera2() without explicitly specifying a camera index. Therefore, physically identify the front navigation camera and confirm the captured view before enabling the drivetrain; do not assume enumeration order remains unchanged after reconnecting CSI cables.
The final physical camera positions are approximately:
Camera | Pose | Role
Front Camera 3 | About 50° downward pitch; about 5 mm right of centre | Wall, marker, and obstacle perception
Rear Camera 3 | About 45° downward pitch; approximately 0° yaw | Rear-wall and parking geometry

Camera geometry is part of calibration. Moving a camera can require retuning colour thresholds and walldetection behavior.

## 7 Verify the software environment

Before applying power to the drivetrain, verify the core imports:

python3 -c "import cv2, numpy, RPi.GPIO; from picamera2 import Picamera2;

print('Core imports OK')"

A successful result is:

Core imports OK

The Open Challenge source currently imports OpenCV, NumPy, RPi.GPIO, and Picamera2. The Obstacle Challenge additionally requires its IMU helper module once that file is published in src/.

## 8 Pre-run checklist

Before every autonomous run, complete the following checks:
1. Check LiPo condition and polarity.

2. Confirm the XT60 connector is fully seated.
3. Confirm the drivetrain rotates freely.
4. Check that the steering linkage is attached correctly.
5. Confirm the wheels are approximately straight at the centre command.
6. Verify the intended camera is detected and showing the correct view.
7. Confirm the front camera angle has not moved.
8. Check motor direction with the driven wheels lifted clear.
9. Check marker and wall detection under current lighting.
10. Keep the main power switch accessible as an emergency cut-off.

## 9 Run the Open Challenge

The current Open Challenge command is:

python3 src/Open_Challenge.py

After startup, the program initializes GPIO and the camera, allows automatic exposure and white balance to settle for approximately two seconds, locks exposure and analogue gain, centres the steering, and starts the drivetrain automatically. The current Open V5 source commands forward(100), equivalent to 100% PWM, so position the robot safely before the autonomous stage begins.
For the first hardware test, lift the driven wheels clear of the surface. For a competition run, place the robot in the correct starting position before executing the program.
The program prints messages such as:

Auto adjusting camera...

Camera locked

Robot Started

CLOCKWISE

The first valid coloured marker determines direction: blue first means anticlockwise, and orange first means clockwise. The first marker establishes direction but is not counted as a completed course event. The program then counts 12 valid crossings for the three-lap run.
To stop manually, click the OpenCV display window so it has keyboard focus, then press q. If the display is unavailable, use the physical emergency power cut rather than relying on keyboard input. The normal stop sequence centres the steering and stops the motor.

## 10 Run the Obstacle Challenge

The intended command is:

python3 src/Obstacle_Challenge.py

Public-code status. The current public GitHub snapshot must not yet be treated as the final reproducible Obstacle/Parking executable. This limitation is intentionally recorded here so the setup guide remains evidence-accurate.

At the current public snapshot:

- Obstacle_Challenge.py imports from heading import MPU6050Heading, but heading.py is not
currently present in src/.
- Parking speed variables are currently ps = 0 and rs = 0.
- The normal steering actuation line is commented in the displayed navigation loop.
Before final competition submission, the repository must include:

src/heading.py

and the exact tested Obstacle and Parking source used on the physical robot. Once those files are synchronized and verified, launch the program from the repository root with the command above. The final executable should reproduce the tested sequence: course navigation, red/green pillar avoidance, lap completion, parking detection, rear-camera/IMU-assisted positioning, and stop.

## 11 Camera startup and safe shutdown

Both current challenge programs allow approximately two seconds for automatic exposure and whitebalance adjustment. The program records ExposureTime and AnalogueGain, then disables automatic exposure and white balance for the remainder of the run. For reproducible results, avoid moving the robot or dramatically changing the lighting during this startup period.
After testing, stop the program normally and shut down Raspberry Pi OS before disconnecting main power when practical:

sudo shutdown -h now

Wait for the Raspberry Pi to shut down before removing power. The physical main switch remains the immediate emergency cut-off if the robot behaves unexpectedly.

## 12 Final repository placement

The recommended repository structure is:

README.md | quick-start summary
requirements.txt | root-level dependencies

src/

Open_Challenge.py

Obstacle_Challenge.py

heading.py | required by Obstacle/Parking

other/

PI_SETUP_AND_RUN.md | detailed version of this guide

Logic design.pdf

Parking Logic Designing.png

The root README.md should contain a short quick-start link to other/PI_SETUP_AND_RUN.md. Keep requirements.txt at the repository root so judges and standard tools can find it immediately.

## 13 Final verification checklist

Before describing the system as fully reproducible, a new team member should be able to clone the repository, install the dependencies, verify cameras and I2C, run the Open Challenge, run the Obstacle Challenge, and execute Parking without requesting missing files or undocumented commands.

Verification item | Completion condition
Repository files | heading.py, final obstacle/parking source, requirements/setup files are public
Hardware | Polarity, common ground, motor-driver path, cameras, IMU, and emergency cut-off verified
Software | Core imports pass and Open/Obstacle/Parking commands run from a clean setup
Calibration | Camera poses, steering limits, lighting, and I2C devices verified
Evidence | Timing sheet, video index, and final release identifier match the engineering journal

Document prepared for Team Sentio WRO Future Engineers 2026 engineering documentation.

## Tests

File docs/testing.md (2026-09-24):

# Starlight Failure Log

**Project:** Starlight  
**Team:** Sentio 6010 
**Competition:** WRO Future Engineers 2026  
**Purpose:** Record observed failures, identify likely causes, document engineering changes, and verify whether each change improved the system.

---

## Why We Keep a Failure Log

Starlight was developed through repeated cycles of:

**Build → Test → Observe → Identify Failure → Modify → Retest**

Many failures crossed subsystem boundaries. A mechanical problem could create an electrical failure, a camera-placement problem could appear to be a software problem, and an incorrect visual interpretation could produce an unsuitable steering command.

For this reason, failures are recorded by **observed symptom, diagnosis, engineering response, and retest result** rather than simply listing whether a run passed or failed.

---

## Failure Register

| ID | Observed Failure | Diagnosis / Cause | Engineering Change | Retest / Current Status |
| --- | --- | --- | --- | --- |
| **F01** | Earlier drive motor stalled under high load | Drivetrain load exceeded the useful operating margin of the earlier motor | Replaced the earlier motor with a **12 V, 600 RPM geared encoder motor** and revised the drivetrain operating point | **Passed**. No recurrence of the same stall was reported in retained final testing |
| **F02** | Motor stall was followed by motor-driver damage | Mechanical stall produced excessive electrical stress through the drive system | Replaced the damaged driver, revised drivetrain loading, and introduced faster power cut-off and inspection during testing | **Passed / Monitored** |
| **F03** | Raspberry Pi undervoltage warnings occurred under load | Earlier regulated supply did not provide sufficient current headroom for the computer and connected electronics | Upgraded the Raspberry Pi supply to a higher-current regulated arrangement | **Passed** in subsequent integrated testing |
| **F04** | Camera perception became unstable in important parts of the course | Camera position and field geometry prevented threshold tuning alone from producing reliable observations | Repositioned cameras, redesigned mounts, fixed the camera pose, and later introduced task-specific vision regions | **Passed / Integrated into final architecture** |
| **F05** | Parts of the robot entered the useful camera view | The chassis/body occupied pixels that could otherwise be interpreted as track features | Added a **body-exclusion mask** and reorganized the useful vision regions | **Passed** in the current vision architecture |
| **F06** | Corner and line features were difficult to observe consistently | Earlier camera placement did not provide enough useful near-field geometry during turns | Cameras were repositioned and mounted more rigidly; the vision system was revised around multiple task-specific ROIs | **Retested and retained** |
| **F07** | Large steering corrections stressed or disconnected the steering linkage | Excessive servo travel and aggressive controller corrections placed unnecessary load on the Ackermann mechanism | Added bounded steering commands and reduced excessive control response | **Passed**. Safe steering limits are enforced by the drive layer |
| **F08** | Red could be interpreted as magenta under warm/yellow lighting | Lighting changed the apparent HSV/LAB colour values enough to confuse two functionally different classes | Recalibrated colour ranges under field lighting and strengthened area/state conditions before accepting critical colour cues | **Retested**. Venue calibration remains part of pre-run setup |
| **F09** | Green-pillar interaction near the inner wall produced insufficient clearance | Pillar detection, local wall geometry, and the active steering state could compete during corner exit | Revised perception regions and obstacle-control logic so pillar information is interpreted with course direction and current state | **Retested / Obstacle logic revised** |
| **F10** | Green obstacle contact occurred during a competition configuration | Correct perception alone did not guarantee sufficient physical clearance during the manoeuvre | Revised obstacle approach geometry, steering behaviour, camera interpretation, and post-Nationals chassis/sensing configuration | **Redesigned and retested** |
| **F11** | Parking/course cue could be detected before the robot was in the intended terminal position | A visible magenta region could satisfy a simple detection condition too early | Added stronger confirmation logic using area/state conditions rather than treating one visual detection as sufficient | **Retested** |
| **F12** | A single short-range distance detection could create an unreliable parking transition | One sensor reading could represent a transient observation rather than a stable parking condition | Added repeated ToF detection with an inter-detection pause before advancing the parking state | **Implemented and retested** |
| **F13** | Parking behaviour differed depending on clockwise or anticlockwise course entry | The robot approached the parking area with different position and heading geometry in the two directions | Added direction-dependent entry logic; the anticlockwise branch repositions the robot before joining the shared final parking routine | **Integrated into final parking architecture** |
| **F14** | Camera-only or time-only parking manoeuvres were sensitive to starting pose and motion variation | Fixed-time turns could produce different final orientations as grip, battery condition, and initial pose changed | Combined vision with **IMU heading feedback** and later **ToF distance sensing** for terminal positioning | **Retained in final architecture** |
| **F15** | Full-robot debugging made it difficult to identify whether a failure came from sensing, steering, movement, or heading | Several modules were being tested simultaneously, hiding the original cause | Created dedicated calibration and component tests for colour, servo motion, encoder response, ToF sensing, and heading | **Passed as development workflow**. Component testing now precedes full runs |

---

## Selected Failure Chains

### F01–F02: Drivetrain Stall → Electrical Failure

The earlier drivetrain demonstrated that a mechanical failure could propagate into the electrical system.

```text
High mechanical load
        ↓
Motor stall
        ↓
High electrical stress
        ↓
Motor-driver damage
        ↓
Motor / drivetrain redesign
        ↓
Low-speed retest
        ↓
Full-system testing
```

The response was therefore not limited to replacing the failed component. The team changed the motor operating point and revised how the drivetrain was tested.

---

### F04–F06: Camera Geometry → Perception Failure

Repeated perception problems showed that threshold values cannot compensate for unsuitable camera geometry.

```text
Track feature difficult to observe
        ↓
Check colour thresholds
        ↓
Threshold adjustment insufficient
        ↓
Inspect camera pose and useful image area
        ↓
Reposition camera / redesign mount
        ↓
Create task-specific ROIs
        ↓
Recalibrate on physical field
```

This led to the current vision architecture in which different image regions have different jobs rather than treating the complete camera frame as one undifferentiated input.

---

### F07: Steering Stress → Command Limits

Testing showed that the software could request steering values beyond what was mechanically useful.

The solution was to make the low-level drive layer responsible for enforcing the safe steering range.

```text
Vision requests large correction
        ↓
Drive layer receives request
        ↓
Request exceeds safe mechanical range?
        ↓
YES → Clamp command
NO  → Send command directly
```

This prevents a high-level control error from automatically becoming a mechanical linkage failure.

---

### F08: Warm Lighting → Red / Magenta Confusion

Red and magenta have very different meanings in the obstacle controller:

- **Red:** Obstacle / pillar information
- **Magenta:** Course-state or parking information

Under warm lighting, the visual separation between these classes became less reliable.

The response included:

1. Recalibrating HSV and LAB ranges under the actual lighting.
2. Rejecting blobs below useful area thresholds.
3. Considering the robot's current state before accepting a magenta event.
4. Using geometry and region information alongside colour.
5. Repeating calibration before competition runs.

This failure demonstrated why colour classification cannot be treated independently from lighting and state logic.

---

### F11–F12: Parking Trigger Reliability

Parking is particularly vulnerable to false transitions because a premature state change can terminate an otherwise successful run.

The parking controller therefore moved away from:

```text
Detection → Immediately act
```

toward:

```text
Detection
    ↓
Check required state / phase
    ↓
Check size or distance condition
    ↓
Confirmation
    ↓
Inter-detection delay where applicable
    ↓
Second qualifying observation
    ↓
Execute parking transition
```

The addition of multiple distance sensors also provides local physical information that does not depend entirely on camera appearance.

---

## Engineering Lessons

The most important failures were rarely isolated to one component.

| Failure Origin | Possible Downstream Effect |
| --- | --- |
| Mechanical load | Motor stall → electrical stress |
| Power instability | Interrupted computation or unreliable sensing |
| Camera position | Incorrect or missing visual observation |
| Colour calibration | Incorrect course-state interpretation |
| Steering command | Mechanical stress or obstacle contact |
| State logic | Correct detection used at the wrong moment |
| Sensor placement | Correct measurement of the wrong physical surface |

The development process therefore treats **mechanics, electronics, perception, and control as one connected system**.

---

## Current Debugging Procedure

When a new failure appears:

1. **Record the observable symptom.**
2. **Do not immediately change several parameters.**
3. Identify the most likely layer:
   - Power
   - Mechanical drive
   - Steering
   - Camera geometry
   - Colour classification
   - Distance sensing
   - Heading
   - State logic
4. Run the relevant component test.
5. Change one meaningful variable.
6. Repeat the same test.
7. Integrate the corrected module at low speed.
8. Run the complete challenge.
9. Record whether the failure:
   - Disappeared
   - Became less frequent
   - Changed form
   - Remained unresolved
10. Commit the verified change so the tested software and documentation remain traceable.

---

## Status Definitions

| Status | Meaning |
| --- | --- |
| **Passed** | The modification removed the recorded failure in retained testing |
| **Retested** | The change was tested physically, but no formal reliability percentage is claimed |
| **Integrated** | The solution forms part of the current robot architecture |
| **Monitored** | The failure has not recently recurred but remains something checked during testing |
| **Calibration required** | Architecture is retained, but values may need adjustment for venue conditions |
| **Open** | Root cause or reliable correction has not yet been established |

---

## Evidence Policy

A successful retest shows that a modification can work. It does **not** automatically establish a statistical reliability percentage.

Where the number of total attempts was not recorded, this log uses terms such as **passed**, **retested**, or **no recurrence observed** rather than inventing a success rate.

Failures are intentionally retained in this document because they show how Starlight changed from an early prototype into the current competition vehicle.

---

**Team Sentio 6010**  
**Starlight | WRO Future Engineers 2026**

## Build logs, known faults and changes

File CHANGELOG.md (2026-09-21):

# Team Sentio — WRO Future Engineers 2026

## Engineering, Software & Validation Changelog

This changelog documents the major engineering milestones, software revisions, calibration work, hardware changes, validation results, and repository updates for **Team Sentio's WRO Future Engineers 2026 vehicle, Starlight**.

The document provides a chronological record of how the robot evolved from early mobility and perception prototypes into the competition-validated Nationals configuration and, subsequently, the redesigned **WRO Asia Pacific Open Championship (APOC)** configuration.

Detailed calculations, failure analysis, testing evidence, design decisions, and supporting engineering rationale remain documented in the engineering journal and associated repository files.

---

# 19 September 2026 — Post-Nationals APOC Redesign & Vision Calibration System

Following the India Nationals build, Starlight entered a new engineering and development cycle focused on preparation for the **WRO Asia Pacific Open Championship (APOC)**.

This revision introduced changes across the mechanical structure, camera architecture, computer vision pipeline, parking system, and calibration workflow. The Nationals configuration remains preserved as the validated competition baseline; the changes below represent the subsequent APOC development branch.

## Development-Version Photographic Record

- Photographs of the major physical development stages are retained in the repository under **`v-photos`**.
- These records document the mechanical evolution of the robot, including:
  - the **fully LEGO prototype**, used during the earliest mobility and mechanism-development stages;
  - the **hybrid LEGO + 3D-printed configuration**, where custom printed components were progressively introduced while retaining LEGO Technic drivetrain and steering elements;
  - the later purpose-built competition chassis.
- The photographs provide visual evidence of the mechanical development lineage documented throughout the project.

## Chassis & Camera-Layout Redesign

After Nationals, the chassis was substantially redesigned for the APOC configuration.

- The previous chassis, camera mounts, and selected printed support structures were replaced.
- The new architecture was designed around a revised sensing arrangement.
- **Both cameras are now positioned toward the rear of the robot.**
- The revised camera geometry provides a wider and more useful view of the competition environment.
- New camera placement required corresponding changes to:
  - printed camera mounts;
  - chassis packaging;
  - camera geometry;
  - custom PLA structures;
  - vision-processing assumptions.
- Camera placement is therefore treated as an integral component of the perception system rather than solely as a mechanical mounting decision.

## Vision-System Redesign

`vision.py` was substantially rewritten for the APOC configuration.

The new architecture moves away from a single broad detection region and instead uses a structured **multi-ROI perception system**.

### Major changes

- Multiple dedicated **Regions of Interest (ROIs)** were introduced.
- Different ROIs are assigned to different portions of the competition environment and different detection tasks.
- Explicit exclusion regions were added to prevent visible robot components, wiring, and other non-field objects from contaminating detections.
- Black-wall processing is performed independently within separate ROIs so detections from different regions are not incorrectly merged.
- Colour detection, black-wall detection, and pillar detection were recalibrated for the new rear-mounted camera geometry.
- Exposure and white-balance stabilization were retained to improve threshold consistency between runs.
- Camera-dependent geometric assumptions were recalculated following the physical camera relocation.

These changes were designed to improve the reliability and repeatability of wall, marker, pillar, and obstacle detection under the revised mechanical configuration.

---

# 19 September 2026 — HSV Calibration & Interactive Vision-Tuning System

A new **interactive colour-calibration system** was added on **19 September 2026** to improve the repeatability and efficiency of computer-vision development.

Previously, colour thresholds were adjusted primarily through repeated manual code edits and robot testing. The new calibration workflow provides a dedicated environment for tuning the vision system before committing threshold values to the main navigation code.

## HSV Slider Calibration

The calibration program introduces interactive **HSV sliders / trackbars** that allow the operator to adjust colour thresholds in real time.

The calibration workflow allows the following parameters to be tuned while viewing the camera feed:

- Hue lower bound;
- Hue upper bound;
- Saturation lower bound;
- Saturation upper bound;
- Value lower bound;
- Value upper bound.

The resulting mask is displayed simultaneously with the camera image, allowing the effect of each threshold adjustment to be evaluated immediately.

### Calibration workflow

```text
Camera Frame
      ↓
Colour-space conversion
      ↓
HSV threshold sliders
      ↓
Live colour mask
      ↓
Visual inspection
      ↓
Threshold refinement
      ↓
Contour / detection verification
      ↓
Final threshold values
      ↓
Integration into vision system
```

This significantly reduces the need to repeatedly modify source code simply to test a new threshold.

## Purpose of the HSV Calibration Tool

The new calibration system was introduced to make the vision-development process more systematic.

It allows the team to:

- identify suitable HSV ranges for competition colours;
- observe how lighting changes affect colour masks;
- remove unwanted background regions;
- distinguish genuine coloured objects from small noise regions;
- tune thresholds for different camera positions;
- rapidly test alternative threshold combinations;
- verify colour separation before integrating values into navigation code.

The calibration tool therefore functions as a **development and validation instrument**, rather than being treated as a separate competition-control algorithm.

## HSV + LAB Vision Development

The calibration workflow complements the existing LAB-based vision pipeline rather than replacing it.

The project continues to use colour-space processing appropriate to the detection task, with HSV providing an intuitive and highly tunable calibration interface and LAB remaining part of the established competition vision architecture.

The development workflow can therefore be represented as:

```text
Camera Image
      ↓
Initial HSV Calibration
      ↓
Threshold Investigation
      ↓
Mask Validation
      ↓
LAB / HSV Vision Pipeline
      ↓
Morphological Filtering
      ↓
Contour Detection
      ↓
Geometric Validation
      ↓
Robot Decision
```

This separation allows calibration to be performed independently from the final navigation logic.

## Calibration as an Engineering Process

The introduction of the HSV slider system also improves reproducibility.

Instead of treating threshold values as arbitrary constants, the team can now:

1. capture the camera view under the intended lighting conditions;
2. adjust HSV ranges interactively;
3. inspect the resulting mask;
4. verify that the desired object is isolated;
5. check that surrounding field elements are rejected;
6. record the resulting threshold values;
7. transfer validated values into the competition vision code;
8. physically test the resulting detection on the robot.

This creates a clearer link between **visual calibration, software implementation, and physical validation**.

---

# 19 September 2026 — APOC Open Challenge Software Revision

The **Open Challenge software** was updated to match the redesigned APOC vision architecture.

- Steering and navigation logic were modified to consume the revised multi-ROI wall and marker detections.
- Camera-dependent thresholds were recalibrated.
- Target positions were updated for the new camera geometry.
- Wall-following assumptions were adjusted to reflect the rear-mounted camera arrangement.
- Vision-processing parameters were reviewed using the new calibration workflow.
- The Open Challenge implementation is therefore a later software revision rather than a direct copy of the Nationals Open V5 implementation.

The APOC Open code should consequently be treated as a dedicated branch of development built around the redesigned perception system.

# 19 September 2026 — APOC Obstacle Challenge Revision

The **Obstacle Challenge software** was also updated for the new vision architecture.

- Obstacle detection was adapted to the revised camera geometry.
- Wall-following behaviour was updated to consume the new multi-ROI detections.
- Detection zones were recalibrated.
- Target geometry was recalculated for the new camera positions.
- Control behaviour was retuned following the chassis redesign.
- Colour and pillar detection were verified against the revised camera feed.

The underlying navigation objective remains continuous visual navigation around red / green pillars, while the perception and control layers have been revised for the APOC configuration.

# Dual ToF Sensing Added for Parking

Two **VL53L0X time-of-flight (ToF) distance sensors** were added to the APOC configuration.

The sensors supplement the existing camera and MPU6050 feedback during parking.

### Primary purpose

The ToF sensors provide direct short-range distance measurements to improve the repeatability of parking stops.

Parking logic therefore no longer depends exclusively on camera geometry, heading feedback, and fixed timing.

The APOC parking implementation includes:

- a startup delay before ToF detection becomes active;
- repeated distance measurements;
- a two-detection confirmation system;
- an inter-detection cooldown;
- ToF-confirmed stopping;
- additional ToF-controlled forward / reverse stopping phases.

The resulting architecture separates the responsibilities of the sensing systems:

```text
CAMERAS
→ Field geometry / visual positioning

VL53L0X ToF
→ Short-range distance / stopping confirmation

MPU6050
→ Heading / orientation

RASPBERRY PI 5
→ Sensor fusion / state logic / control

MOTOR + ACKERMANN STEERING
→ Physical execution
```

# APOC Sensing Architecture

```text
        2 × REAR-MOUNTED CAMERAS
                   ↓
        MULTI-ROI COMPUTER VISION
                   ↓
        WALL / MARKER / PILLAR DATA
                   ↓
           OPEN + OBSTACLE
             NAVIGATION

          2 × VL53L0X ToF
                   ↓
       SHORT-RANGE DISTANCE DATA
                   ↓
          PARKING STOP LOGIC

              MPU6050
                 ↓
        HEADING / ORIENTATION
                 ↓
          STATE ESTIMATION

           RASPBERRY PI 5
                 ↓
      SENSOR FUSION + CONTROL
                 ↓
       MOTOR + ACKERMANN STEERING
```

# APOC Revision Status

The APOC configuration should be treated as a **post-Nationals engineering revision** and not as a retroactive description of the Nationals robot.

The Nationals V3 / Open V5 configuration remains the documented and physically validated competition baseline.

The September APOC revision represents a new development stage involving:

- redesigned chassis;
- revised rear-mounted camera architecture;
- multi-ROI vision;
- new HSV calibration tooling;
- recalibrated colour detection;
- revised Open Challenge software;
- revised Obstacle Challenge software;
- dual ToF parking sensors;
- updated parking-distance logic.

---

# 24 August 2026 — Final Competition Validation

## Obstacle Challenge & Parking

- Final Obstacle Challenge software completed physical robot testing successfully.
- Final parking behaviour was also physically tested and was working.
- The working challenge code and required helper modules were pushed to GitHub.
- The final project package included:
  - `drive.py`
  - `vision.py`
  - `openVision.py`
  - `heading.py`
  - `parking.py`
- The final repository represented the working robot software rather than a development-only snapshot.
- Later field-calibration changes were intended to be committed and pushed so the Raspberry Pi and repository remained synchronized.

# 18 August 2026 — Repository Documentation & Reproducibility Update

## Added

- Added `src/heading.py` for MPU6050 heading integration.
- Added `requirements.md` as the formal software dependency record.
- Added `docs/Software_Dependencies.md`.
- Added `docs/pi_setup_instruction.md` containing Raspberry Pi setup, GPIO, I2C, camera, package-installation, safety, and run instructions.

## Updated

- Expanded `README.md` into the primary repository-level engineering and reproduction guide.
- Synchronized the README with the Rev6 Open Challenge evidence.
- Documented:
  - **12 successful timed runs**;
  - **22 s best observed time**;
  - five video-backed tests from 15 August 2026.
- Added clearer links between source code, CAD, wiring, photographs, videos, dependencies, and setup documentation.
- Added exact-source reproducibility guidance linking the physically validated executable to a Git commit.

## Repository Status

- Open Challenge documentation and dependency packaging were completed.
- Obstacle Challenge and Parking completed physical validation.
- The complete working project package and helper modules were pushed to GitHub.
- The repository could therefore be treated as the final competition project package, subject to later field-calibration revisions.

# Rev6 Submission / Release Candidate — Evidence Freeze: 16 August 2026

## Mechanical V3

The final competition-focused mechanical platform was recorded as **V3**.

### Final recorded dimensions

| Parameter | Value |
|---|---:|
| Mass | 865 g |
| Length | 210 mm |
| Width | 128 mm |
| Height | 265 mm |
| Wheelbase | 107.5 mm |
| Track width | 110 mm |
| Wheel diameter | 46 mm |
| Ground clearance | 14 mm |

- Purpose-built PLA structures were retained where repeatable geometry was required.
- Selected LEGO Technic elements were retained where serviceability, steering adjustment, and rapid replacement were beneficial.
- The final steering architecture used **Ackermann steering**.

### Final Open steering limits

```text
LEFT   = 70
CENTER = 95
RIGHT  = 125
```

Wider servo travel was rejected after testing indicated increased linkage stress and a greater possibility of mechanical disconnection.

## Drivetrain Redesign

- The earlier **1000 RPM Johnson geared motor** was replaced after heavy loading and stall behaviour.
- The damaged TB6612FNG motor driver was replaced.
- The final configuration adopted a **JGB37-520, 12 V, 600 RPM motor**.
- The **36T driving → 24T driven** external gear stage was retained.
- The design prioritised repeatability and drivetrain reliability over maximum rated motor speed.
- No recurrence of the earlier motor-stall / driver-failure pattern was reported in the retained final testing.

## CAD & Mechanical Reproducibility

The final custom PLA structures were documented as Onshape-designed components.

The repository mechanical evidence included:

- six CAD render images;
- two printable STL files;
- one compressed GLB assembly/model.

Printed parts were used to preserve repeatable geometry for the camera, electronics, drivetrain, and other integrated components.

## Power Architecture

The final Nationals configuration retained a **3S 11.1 V 2200 mAh LiPo**.

Recorded charged-pack voltage: **approximately 12.2 V**.

The earlier **5 V / 3 A Raspberry Pi supply arrangement** was replaced after repeated undervoltage warnings.

A higher-current regulated 5 V Raspberry Pi supply architecture was introduced.

The common-ground architecture between the control electronics, sensors, and motor-driver references was retained.

## Electrical & Safety Engineering Changes

The project incorporated several safety-driven engineering changes following observed failures.

- Stricter charging supervision and correct 3S / cell-count checks were introduced following an earlier LiPo charging incident.
- Explicit polarity checks were introduced.
- A safer keyed / polarised connector strategy was adopted following reverse-polarity incidents.
- Faster power cut-off procedures were introduced.
- Staged drivetrain checks were added following the motor-stall / driver-failure event.
- These changes were documented as engineering responses to observed failure modes rather than undocumented assumptions.

# Nationals Camera & Sensing Architecture

The final V3 Nationals sensing stack consisted of:

- 2 × Raspberry Pi Camera Module 3;
- MPU6050 IMU;
- SSD1306 OLED;
- front illumination LED.

### Recorded camera geometry

**Front camera**

- approximately 5 mm right of centre;
- approximately 50° downward pitch.

**Rear camera**

- approximately 45° downward pitch;
- approximately 0° yaw.

Camera geometry was revised after earlier positions produced unstable corner-wall detection and late line detection.

### Startup image calibration

The final V3 startup procedure retained:

1. AE/AWB enabled for approximately 2 seconds;
2. exposure and analogue gain captured;
3. AE/AWB disabled;
4. fixed LAB thresholds used during the run.

This was intended to reduce colour-threshold instability caused by changing exposure and white balance.

The Nationals V3 configuration did **not** claim LiDAR, ultrasonic sensing, or wheel encoders.

The later APOC configuration subsequently added **2 × VL53L0X ToF sensors** for parking-distance feedback and changed the camera/chassis architecture as documented in the September revision.

# Open V5 — Final Nationals Open Challenge Control

## Control Architecture

The final Nationals Open Challenge software was retained as **Open V5**.

### Camera stream

```text
1280 × 680
RGB888
```

### Image-processing pipeline

```text
Frame
  ↓
Gaussian Blur
  ↓
LAB Conversion
  ↓
CLAHE
  ↓
Colour Masks
  ↓
Morphological Filtering
  ↓
Contours
  ↓
Geometry
  ↓
Proportional Steering
```

# Direction Logic

The first valid marker established the driving direction:

```text
Blue first   → Anticlockwise
Orange first → Clockwise
```

The first valid marker established direction but did not increment the lap count.

# Wall-Following Redesign

The earlier symmetric two-wall centring strategy was rejected after testing revealed corner meandering and asymmetric-wall visibility problems.

The final Open V5 architecture retained direction-aware wall following:

- **Both walls visible** → proportional geometric error;
- **One wall visible** → direction-aware single-wall target;
- **No wall visible** → small directional fallback.

# Final Open Tuning

```text
KP = 0.012
LINE_COOLDOWN = 1.3 s
```

Testing documented the following observations:

- `KP = 0.010` was too weak.
- `KP = 0.015–0.020` produced more aggressive steering and increased linkage stress.
- `KP = 0.050` was excessively aggressive.
- `LINE_COOLDOWN = 0.8 s` was too short and could allow duplicate counting.
- Values approaching `1.8 s` were more likely to miss genuine crossings.
- `1.3 s` was retained as the observed compromise.

# Lap Counting & Stop Logic

The final Open V5 implementation retained:

**3 laps × 4 counted events = 12 events**

A rising-edge marker detection system was used so that a single physical marker remaining visible across multiple frames was counted only once.

After 12 counted events:

```text
Steering → Centre
Motor    → Stop
Control Loop → Terminate
```

# Open Challenge Performance Evidence

Rev6 records:

- **12 successful timed Open Challenge runs**
- **22 s best observed time**

Five additional video-backed tests from 15 August 2026 were recorded as:

| ID | Speed Command | Time |
|---|---:|---:|
| V-01 | 100 | 23 s |
| V-02 | 90 | 29 s |
| V-03 | 90 | 28 s |
| V-04 | 100 | 22 s |
| V-05 | 100 | 23 s |

No causal claim is made that speed command alone produced the observed timing differences because direction, battery state, lighting, and track state were not fully controlled for every run.

No Open Challenge success probability is claimed because a complete failed-attempt denominator was not retained.

# Obstacle Challenge Strategy Development

## Navigation Redesign

The earlier fixed / early obstacle-turn strategy was rejected following repeated corner-pillar collision and run-over failures.

The system was redesigned around a **continuous visual target** strategy.

- Pillar target position changes continuously according to image geometry.
- Vertical position / proximity modifies the target as the pillar approaches.
- Steering continuously tracks the selected passing target.
- Once the obstacle is no longer relevant, the controller rejoins direction-aware wall-following.
- Lower obstacle speed was retained to provide additional time for perception and steering corrections.

### Obstacle State Architecture

```text
Perceive
   ↓
Identify Relevant Pillar
   ↓
Choose Passing Target
   ↓
Continuously Steer
   ↓
Rejoin Wall Following
   ↓
Complete Course
   ↓
Parking Stage
```

# Obstacle Challenge Validation

- More than **10 successful full Obstacle Challenge runs** were reported during development.
- The final Obstacle Challenge framework completed physical robot testing successfully.
- The exact submitted software package, including required helper modules, was retained in the final GitHub project.
- The complete failed-attempt denominator was not retained; therefore, no obstacle success percentage is claimed.

# Parking Architecture Development

The parking architecture evolved from a single opaque manoeuvre into a sequence of controlled Ackermann-compatible corrections.

The rear camera remained the primary collision-critical parking view, while the MPU6050 provided relative orientation feedback.

### Intended parking sequence

```text
Course Complete
      ↓
Locate Parking Geometry
      ↓
Reverse Entry
      ↓
IMU-Assisted Counter-Steer
      ↓
Re-Observe Rear Geometry
      ↓
Short Forward / Reverse Correction
      ↓
Confirm Position & Heading
      ↓
Stop
```

Because the robot uses Ackermann steering, non-zero forward / reverse movement is required; the chassis cannot rotate in place.

The parking architecture is intended to use repeated observations rather than relying on one long open-loop reverse movement.

The final Nationals Obstacle / Parking behaviour completed physical robot validation successfully.

# Development Lineage

The Rev6 engineering record preserves the following development sequence. Photographs of the **fully LEGO** and later **hybrid LEGO + 3D-printed** versions are retained in `v-photos` as visual evidence of this progression.

## V0 — LEGO Mobility

- Initial LEGO-dominant mobility architecture.
- Established basic vehicle movement before the final purpose-built chassis.

## V1 — Circuit + Camera

- Added working electronics.
- Introduced camera-based control development.

## V2 — Printed Electronics Mount

- Introduced a 3D-printed electronics mounting architecture.
- Improved packaging repeatability and integration.

## V3 — Purpose-Built Competition Chassis

- Introduced the competition-focused chassis architecture.
- Added purpose-built PLA packaging.
- Retained serviceable LEGO Technic steering / drivetrain components where useful.
- Integrated dual-camera geometry and the documented IMU / display sensor stack.

## Open V5 — Final Nationals Open Control

- Finalised direction-aware Open Challenge control.
- Retained `KP = 0.012`.
- Retained `LINE_COOLDOWN = 1.3 s`.
- Retained rising-edge marker counting.
- Retained 12-event completion logic.
- Documented 12 successful timed runs with a 22 s best.

## APOC Revision — September 2026

- Redesigned chassis and camera layout.
- Moved both cameras toward the rear.
- Introduced multi-ROI vision.
- Added explicit exclusion regions.
- Recalibrated wall, marker, pillar, and colour detection.
- Added interactive **HSV slider calibration** on 19 September.
- Retuned the vision system using the new calibration workflow.
- Revised Open Challenge and Obstacle Challenge software.
- Added **2 × VL53L0X ToF sensors** for parking-distance feedback.
- Revised parking logic around direct distance confirmation.
- Continued integration of camera, ToF, IMU, and Raspberry Pi control into a unified sensing architecture.

# Engineering Revision Summary

| Date | Major Revision | Primary Outcome |
|---|---|---|
| Early development | LEGO mobility and initial electronics | Basic robot movement established |
| V1 | Camera-based development | Visual control introduced |
| V2 | 3D-printed electronics integration | Improved packaging and repeatability |
| V3 | Competition chassis | Final Nationals mechanical architecture |
| Open V5 | Open Challenge control | Direction-aware wall following and 12-event completion |
| 16 Aug | Rev6 evidence freeze | Competition release candidate documented |
| 18 Aug | Repository / reproducibility update | Software package and documentation consolidated |
| 24 Aug | Final competition validation | Obstacle Challenge and Parking physically validated |
| **19 Sep** | **APOC redesign + HSV calibration** | **New chassis, rear-camera architecture, multi-ROI vision, interactive HSV calibration and revised parking sensing** |

# Current Engineering Status

The project has progressed from a competition-validated Nationals platform into a dedicated APOC development configuration.

The September 2026 revision represents a broader engineering cycle in which the team is redesigning the relationship between:

**mechanical geometry → camera placement → calibration → perception → navigation → parking → validation.**

The addition of the interactive HSV calibration system on **19 September 2026** formalises the vision-development process by allowing colour thresholds to be experimentally calibrated and validated before being integrated into the robot's navigation software.

This provides a clearer and more reproducible workflow for continued development toward APOC.

---

**Team Sentio**  
**WRO Future Engineers 2026**  
**Robofun Lab (RFL), India**

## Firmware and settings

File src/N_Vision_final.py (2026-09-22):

# WRO FINAL COMBINED VISION - RASPBERRY PI
# Resolution: 640 x 360
#
# Final combined version:
# - Keeps every ROI from the current 640x360 vision code
# - One HARD robot exclusion ROI covers the full visible black robot/body region
# - Separate HARD wire exclusion ROI covers the bottom-right wire
# - Exclusions apply to RED/GREEN/BLUE/ORANGE/MAGENTA/BLACK,
#   black-wall detection and black-pillar detection
# - Black detection uses darkness in HSV Value + LAB L
# - Camera AE/AWB settles for 1 s and is then locked when supported
# - Orange/Blue are constrained to ORANGE_BLUE_ROI
# - Duplicate wall/pillar detections are suppressed
#
# Controls:
#   Q / ESC = quit
#   M       = show/hide masks
#   S       = save screenshot

import cv2
from picamera2 import Picamera2
import numpy as np
import time


# ============================================================
# CAMERA
# ============================================================

WIDTH = 720
HEIGHT = 360
FPS = 60

CALIBRATION_SECONDS = 1.0

CALIBRATED_EXPOSURE = None
CALIBRATED_WB = None


# ============================================================
# TOP EXCLUSION
# ============================================================

TOP_BLACK_HEIGHT = 0

TOP_BLACK_ROI = (
    0,
    0,
    WIDTH,
    TOP_BLACK_HEIGHT
)

DETECTION_Y_START = TOP_BLACK_HEIGHT


# ============================================================
# HSV RANGES
# ============================================================

RED1_LOWER = np.array(
    [0, 115, 42],#[0, 115, 65],
    dtype=np.uint8
)

RED1_UPPER = np.array(
    [8, 255, 155],#[8, 255, 255],
    dtype=np.uint8
)

RED2_LOWER = np.array(
    [172, 115, 42],#[172, 115, 65],
    dtype=np.uint8
)

RED2_UPPER = np.array(
    [180, 255, 155],#[180, 255, 255],
    dtype=np.uint8
)

GREEN_LOWER = np.array(
    [47, 115, 89],#[51,102,91], #[49,56,88], #[49, 56, 88],
    dtype=np.uint8
)

GREEN_UPPER = np.array(
    [66, 185, 198],#[74, 190, 193], #[71, 163, 188],
    dtype=np.uint8
)


ORANGE_LOWER = np.array(
    [14, 20, 100],
    dtype=np.uint8
)

ORANGE_UPPER = np.array(
    [53, 209, 200],
    dtype=np.uint8
)


BLUE_LOWER = np.array(
    [100, 93, 81],
    dtype=np.uint8
)

BLUE_UPPER = np.array(
    [117, 227, 161],
    dtype=np.uint8
)


MAGENTA_LOWER = np.array(
    [161, 122, 72],
    dtype=np.uint8
)

MAGENTA_UPPER = np.array(
    [171, 241, 166],#[171, 241, 166],
    dtype=np.uint8
)


# Robust black definition.
# Pixel must be dark in BOTH HSV Value and LAB L.
BLACK_MAX_V = 85#100 
BLACK_MAX_L = 95#105 


# ============================================================
# ALL EXISTING ROIs
# ============================================================

LEFT_1_ROI = (
    0,
    0,
    105,
    HEIGHT - 20
)

LEFT_2_ROI = (
    150,
    150,
    200,
    HEIGHT - 100
)


RIGHT_1_ROI = (
    #130 - parking
    WIDTH - 105,
    0,
    WIDTH,
    HEIGHT - 20
)

RIGHT_2_ROI = (
    WIDTH - 200,
    150,
    WIDTH - 150,
    HEIGHT - 100
)


CENTER_BLACK_ROI = (
    320,
    20,
    WIDTH - 320,
    70
)

ORANGE_BLUE_ROI = (
    260,
    120,
    WIDTH -260,
    150
)

# MAGENTA_ROI = (
#     340,
#     200,
#     380,
#     235
#)
# PILLAR_ROI = (
#     35,
#     TOP_BLACK_HEIGHT + 10,
#     WIDTH - 35,
#     HEIGHT - 18
# )
PILLAR_ROI = (
    0,
    TOP_BLACK_HEIGHT + 10,
    WIDTH - 35,
    0
)


# ============================================================
# CRASH ZONE
# ============================================================

CRASH_ZONE_ROI = (
    200,
    170,
    WIDTH - 200,
    HEIGHT - 70
)


BLACK_ROIS = {
    "LEFT WALL": LEFT_1_ROI,

    "LEFT INNER": LEFT_2_ROI,

    "CENTER BLACK": CENTER_BLACK_ROI,

    "RIGHT INNER": RIGHT_2_ROI,

    "RIGHT WALL": RIGHT_1_ROI,
}


# ============================================================
# HARD ROBOT / WIRE EXCLUSIONS
# ============================================================
#
# IMPORTANT:
#
# Nothing inside either of these boxes can ever participate
# in ANY detection.
#
# ROBOT:
# One rectangle covers the complete visible black robot/body
# region from the screenshot, including the black protruding
# part on the lower-left.
#
# WIRE:
# Separate box for the bottom-right visible wire/hardware.
#

ROBOT_EXCLUSION_ROI = (
    200,
    HEIGHT- 70,
    WIDTH-200,
    HEIGHT
)


WIRE_EXCLUSION_ROI = (
    0,
    0,
    0,
    0
)


EXCLUSION_ROIS = [
    TOP_BLACK_ROI,

    ROBOT_EXCLUSION_ROI,

    WIRE_EXCLUSION_ROI,
]


# ============================================================
# DETECTION PARAMETERS
# ============================================================

MIN_CONFIDENCE = 0.55


MIN_AREA = {
    "RED": 300,

    "GREEN": 300,

    "BLUE": 20,#250

    "ORANGE": 20,#250

    "MAGENTA": 500,

    "BLACK": 250,
}


# ============================================================
# BLACK WALL FILTERS
# ============================================================

BLACK_MIN_AREA = 100

BLACK_MIN_WIDTH = 8

BLACK_MIN_HEIGHT = 6

BLACK_MIN_ASPECT = 0.45

BLACK_MAX_ASPECT = 8.0

BLACK_MIN_RECTANGULARITY = 0.20

BLACK_MIN_ROI_FILL = 0.002
BLACK_MIN_CONFIDENCE = 0.15


# ============================================================
# BLACK PILLAR FILTERS
# ============================================================

PILLAR_MIN_AREA = 500

PILLAR_MIN_WIDTH = 12

PILLAR_MIN_HEIGHT = 35

PILLAR_MIN_ASPECT = 1.15

PILLAR_MAX_ASPECT = 7.0

PILLAR_MIN_RECTANGULARITY = 0.32

PILLAR_MIN_DARK_RATIO = 0.55

PILLAR_MAX_CANDIDATES = 3


# Prevent the same black wall contour from also being
# reported as a BLACK PILLAR.
PILLAR_WALL_DUPLICATE_IOU = 0.30


KERNEL = cv2.getStructuringElement(
    cv2.MORPH_ELLIPSE,
    (7, 7)
)


# ============================================================
# LAB REFERENCES
# ============================================================

LAB_REFERENCE = {
    "RED": np.array(
        [194, 114, 139,],#[136, 208, 195],
        dtype=np.float32
    ),

    "GREEN": np.array(
        [150, 80, 170],
        dtype=np.float32
    ),

    "BLUE": np.array(
        [90, 180, 70],
        dtype=np.float32
    ),

    "ORANGE": np.array(
        [170, 150, 210],
        dtype=np.float32
    ),

    "MAGENTA": np.array(
        [150, 210, 120],
        dtype=np.float32
    ),
}


LAB_TOLERANCE = {
    "RED": 85,

    "GREEN": 85,

    "BLUE": 85,

    "ORANGE": 90,

    "MAGENTA": 90,
}


# ============================================================
# CAMERA
# ============================================================

def start_camera():

    """
    Start the camera using the same two-phase calibration approach
    as the previous working vision system.

    Phase 1:
        AE + AWB are explicitly enabled and allowed to settle for
        one second while the camera sees the actual competition field.

    Phase 2:
        The settled ExposureTime, AnalogueGain and ColourGains are
        read from camera metadata, applied back to the camera, and
        AE + AWB are then disabled so the values remain locked during
        the run.
    """

    global CALIBRATED_EXPOSURE
    global CALIBRATED_WB

    picam2 = Picamera2()

    config = picam2.create_video_configuration(
        main={
            "size": (
                WIDTH,
                HEIGHT
            ),
            "format": "BGR888"
        },
        controls={
            "FrameRate": FPS,
            "AeEnable": True,
            "AwbEnable": True,
        }
    )

    picam2.configure(config)
    picam2.start()

    # --------------------------------------------------------
    # PHASE 1: AUTO EXPOSURE + AUTO WHITE BALANCE
    # --------------------------------------------------------
    # Explicitly enable both automatic systems after start as well.
    # This guarantees the camera is allowed to adapt to the field
    # before we capture the calibration values.
    # --------------------------------------------------------
    picam2.set_controls({
        "AeEnable": True,
        "AwbEnable": True,
    })

    time.sleep(CALIBRATION_SECONDS)

    try:
        # Read the values calculated by AE/AWB after the one-second
        # settling period.
        metadata = picam2.capture_metadata()

        exposure = metadata.get("ExposureTime")
        gain = metadata.get("AnalogueGain")
        wb = metadata.get("ColourGains")

        # ----------------------------------------------------
        # PHASE 2: APPLY SETTLED VALUES AND LOCK THEM
        # ----------------------------------------------------
        controls = {
            "AeEnable": False,
            "AwbEnable": False,
        }

        if exposure is not None:
            controls["ExposureTime"] = int(exposure)

        if gain is not None:
            controls["AnalogueGain"] = float(gain)

        if wb is not None:
            controls["ColourGains"] = tuple(wb)

        picam2.set_controls(controls)

        CALIBRATED_EXPOSURE = {
            "ExposureTime": exposure,
            "AnalogueGain": gain,
        }

        CALIBRATED_WB = wb

        print(
            "Camera calibrated and locked: "
            f"ExposureTime={exposure}, "
            f"AnalogueGain={gain}, "
            f"ColourGains={wb}"
        )

    except Exception as exc:
        print(f"Camera lock warning: {exc}")

    return picam2


# ============================================================
# ROI / MASK HELPERS
# ============================================================

def rectangle_mask(
    shape,
    roi
):

    x1, y1, x2, y2 = roi


    x1 = max(
        0,
        min(
            shape[1],
            int(x1)
        )
    )


    x2 = max(
        0,
        min(
            shape[1],
            int(x2)
        )
    )


    y1 = max(
        0,
        min(
            shape[0],
            int(y1)
        )
    )


    y2 = max(
        0,
        min(
            shape[0],
            int(y2)
        )
    )


    mask = np.zeros(
        shape[:2],
        dtype=np.uint8
    )


    if (
        x2 > x1 and
        y2 > y1
    ):

        mask[
            y1:y2,
            x1:x2
        ] = 255


    return mask


def build_allowed_detection_mask(
    shape
):

    """
    255 = detection allowed.

    0 = absolutely forbidden.

    This is the master hard-exclusion mask.
    """

    allowed = np.full(
        shape[:2],
        255,
        dtype=np.uint8
    )


    for roi in EXCLUSION_ROIS:

        x1, y1, x2, y2 = roi


        x1 = max(
            0,
            min(
                shape[1],
                int(x1)
            )
        )


        x2 = max(
            0,
            min(
                shape[1],
                int(x2)
            )
        )


        y1 = max(
            0,
            min(
                shape[0],
                int(y1)
            )
        )


        y2 = max(
            0,
            min(
                shape[0],
                int(y2)
            )
        )


        if (
            x2 > x1 and
            y2 > y1
        ):

            allowed[
                y1:y2,
                x1:x2
            ] = 0


    return allowed


def clean_mask(
    mask
):

    mask = cv2.morphologyEx(
        mask,

        cv2.MORPH_OPEN,

        KERNEL
    )


    mask = cv2.morphologyEx(
        mask,

        cv2.MORPH_CLOSE,

        KERNEL
    )


    return mask


# ============================================================
# MASK CREATION
# ============================================================

def make_color_masks(
    hsv,
    lab,
    allowed_mask
):

    masks = {}


    red1 = cv2.inRange(
        hsv,

        RED1_LOWER,

        RED1_UPPER
    )


    red2 = cv2.inRange(
        hsv,

        RED2_LOWER,

        RED2_UPPER
    )


    masks["RED"] = clean_mask(

        cv2.bitwise_or(
            red1,
            red2
        )
    )


    masks["GREEN"] = clean_mask(

        cv2.inRange(
            hsv,

            GREEN_LOWER,

            GREEN_UPPER
        )
    )


    masks["ORANGE"] = clean_mask(

        cv2.inRange(
            hsv,

            ORANGE_LOWER,

            ORANGE_UPPER
        )
    )


    masks["BLUE"] = clean_mask(

        cv2.inRange(
            hsv,

            BLUE_LOWER,

            BLUE_UPPER
        )
    )


    masks["MAGENTA"] = clean_mask(

        cv2.inRange(
            hsv,

            MAGENTA_LOWER,

            MAGENTA_UPPER
        )
    )


    # --------------------------------------------------------
    # BLACK
    # --------------------------------------------------------
    #
    # Black hue is unstable and essentially meaningless.
    #
    # Instead:
    #
    #   HSV V <= BLACK_MAX_V
    #
    # AND
    #
    #   LAB L <= BLACK_MAX_L
    #

    black = np.where(

        (
            hsv[:, :, 2] <=
            BLACK_MAX_V
        )
        &
        (
            lab[:, :, 0] <=
            BLACK_MAX_L
        ),

        255,

        0

    ).astype(
        np.uint8
    )


    masks["BLACK"] = clean_mask(
        black
    )


    # --------------------------------------------------------
    # HARD EXCLUSION
    # --------------------------------------------------------
    #
    # Applied AFTER morphology.
    #
    # Every mask is guaranteed to be zero in:
    #
    # robot exclusion
    # wire exclusion
    # top exclusion
    #

    for name in masks:

        masks[name] = cv2.bitwise_and(

            masks[name],

            allowed_mask
        )


    return masks


# ============================================================
# GEOMETRY
# ============================================================

def geometry_score(
    contour
):

    area = cv2.contourArea(
        contour
    )


    if area <= 0:

        return 0.0


    _, _, w, h = (
        cv2.boundingRect(
            contour
        )
    )


    if (
        w <= 0 or
        h <= 0
    ):

        return 0.0


    fill = (
        area /
        float(
            w * h
        )
    )


    hull = cv2.convexHull(
        contour
    )


    hull_area = cv2.contourArea(
        hull
    )


    solidity = (
        area /
        float(
            max(
                hull_area,
                1.0
            )
        )
    )


    fill_score = np.clip(
        fill / 0.55,
        0.0,
        1.0
    )


    solidity_score = np.clip(
        solidity / 0.75,
        0.0,
        1.0
    )


    return float(

        0.65 * fill_score
        +
        0.35 * solidity_score
    )


# ============================================================
# LAB SCORE
# ============================================================

def lab_score(
    frame_lab,
    contour,
    color_name
):

    if (
        color_name not in
        LAB_REFERENCE
    ):

        return 1.0


    mask = np.zeros(
        frame_lab.shape[:2],
        dtype=np.uint8
    )


    cv2.drawContours(
        mask,

        [contour],

        -1,

        255,

        -1
    )


    pixels = frame_lab[
        mask > 0
    ]


    if len(
        pixels
    ) == 0:

        return 0.0


    # Limit pixel workload while keeping
    # a stable median measurement.

    step = max(
        1,

        len(pixels) //
        2048
    )


    median_lab = np.median(

        pixels[
            ::step
        ],

        axis=0

    ).astype(
        np.float32
    )


    distance = np.linalg.norm(

        median_lab
        -
        LAB_REFERENCE[
            color_name
        ]
    )


    score = (
        1.0
        -
        distance /
        LAB_TOLERANCE[
            color_name
        ]
    )


    return float(

        np.clip(
            score,
            0.0,
            1.0
        )
    )


# ============================================================
# HSV SCORE
# ============================================================

def hsv_score(
    hsv,
    contour,
    color_name
):

    mask = np.zeros(
        hsv.shape[:2],
        dtype=np.uint8
    )


    cv2.drawContours(
        mask,

        [contour],

        -1,

        255,

        -1
    )


    pixels = hsv[
        mask > 0
    ]


    if len(
        pixels
    ) == 0:

        return 0.0


    med_s = float(

        np.median(
            pixels[:, 1]
        )
    )


    med_v = float(

        np.median(
            pixels[:, 2]
        )
    )


    if color_name == "RED":

        s = np.clip(
            (med_s - 70) / 100,
            0.0,
            1.0
        )


        v = np.clip(
            (med_v - 45) / 100,
            0.0,
            1.0
        )


        return float(
            0.65 * s
            +
            0.35 * v
        )


    if color_name == "GREEN":

        s = np.clip(
            (med_s - 50) / 100,
            0.0,
            1.0
        )


        v = np.clip(
            (med_v - 30) / 100,
            0.0,
            1.0
        )


        return float(
            0.60 * s
            +
            0.40 * v
        )


    s = np.clip(
        (med_s - 40) / 120,
        0.0,
        1.0
    )


    v = np.clip(
        (med_v - 30) / 120,
        0.0,
        1.0
    )


    return float(
        0.60 * s
        +
        0.40 * v
    )


# ============================================================
# CONFIDENCE
# ============================================================

def calculate_confidence(
    lab,
    hsv,
    contour,
    color_name
):

    geom = geometry_score(
        contour
    )


    hsv_s = hsv_score(
        hsv,
        contour,
        color_name
    )


    lab_s = lab_score(
        lab,
        contour,
        color_name
    )


    if color_name in (
        "RED",
        "GREEN"
    ):

        confidence = (

            0.60 * hsv_s
            +
            0.20 * lab_s
            +
            0.20 * geom
        )


    else:

        confidence = (

            0.45 * hsv_s
            +
            0.30 * lab_s
            +
            0.25 * geom
        )


    return float(

        np.clip(
            confidence,
            0.0,
            1.0
        )
    )


# ============================================================
# COLOR DETECTION
# ============================================================

def detect_color(
    hsv,
    lab,
    mask,
    color_name
):

    contours, _ = cv2.findContours(

        mask,

        cv2.RETR_EXTERNAL,

        cv2.CHAIN_APPROX_SIMPLE
    )


    best = None


    for contour in contours:

        area = cv2.contourArea(
            contour
        )


        if (
            area <
            MIN_AREA[
                color_name
            ]
        ):

            continue


        confidence = calculate_confidence(

            lab,

            hsv,

            contour,

            color_name
        )


        if (
            confidence <
            MIN_CONFIDENCE
        ):

            continue


        # Combines confidence with meaningful size.
        #
        # Prevents one large weak contour from
        # automatically beating a clean object.

        score = (

            confidence
            *
            np.sqrt(
                max(
                    area,
                    1.0
                )
            )
        )


        if (
            best is None
            or
            score > best[0]
        ):

            best = (

                score,

                contour,

                confidence,

                area
            )


    if best is None:

        return None


    (
        _,
        contour,
        confidence,
        area
    ) = best


    x, y, w, h = cv2.boundingRect(
        contour
    )


    return {
        "color": color_name,

        "contour": contour,

        "bbox": (
            x,
            y,
            w,
            h
        ),

        "area": area,

        "confidence": confidence,
    }


# ============================================================
# BLACK WALL DETECTION
# ============================================================
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

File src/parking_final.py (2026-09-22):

import cv2
import time
from time import sleep
from picamera2 import Picamera2
from heading import MPU6050Heading
import driveEnc as drive 
import N_VisionP_22 as vision
import N_TOF_19 as TUF

LEFT = drive.LEFT
RIGHT = drive.RIGHT
CENTER = drive.CENTER
# ============================================================
# SETTINGS
# ============================================================

clockwise = False

# Right wall follow distance/position
BLACK_FOLLOW = 150

# Robot speed
RS = 25

# Steering gain
KP = 0.4

# TOF threshold
# 200 mm = 20 cm
TOF_STOP_DISTANCE = 200

# NEW: Time before TOF starts detecting
TOF_START_DELAY = 3.0

# TOF detection cooldown BETWEEN detection #1 and #2
TOF_COOLDOWN = 1.2

CENTER = CENTER

# Vision resolution
WIDTH = vision.WIDTH
HEIGHT = vision.HEIGHT
X_MID = WIDTH // 2

FPS = 60


# ============================================================
# PARKING
# ============================================================

def run_parking_clockwise():

    imu = MPU6050Heading()
    last_heading_time = 0

    tof_detect_count = 0
    last_tof_detection_time = 0.0

    front_cam = Picamera2(0)

    front_config = front_cam.create_video_configuration(
        main={
            "size": (WIDTH, HEIGHT),
            "format": "RGB888"
        },
        controls={
            "FrameRate": FPS
        }
    )

    front_cam.configure(front_config)
    front_cam.start()

    sleep(2)

    print("==========================================")
    print("RIGHT WALL FOLLOW PARKING")
    print("==========================================")
    print("Vision          : N_Vision_9_18")
    print("Wall            : RIGHT BLACK WALL ONLY")
    print("Right D-Zone    : TURN LEFT")
    print("TOF             : TWO DETECTIONS REQUIRED")
    print(f"TOF Start Delay : {TOF_START_DELAY} seconds")
    print(f"TOF Cooldown    : {TOF_COOLDOWN} seconds")
    print(f"TOF Distance    : {TOF_STOP_DISTANCE} mm")
    print("1st TOF         : CONTINUE")
    print("2nd TOF         : STOP")
    print("Q               : STOP")
    print("==========================================")

    drive.steer(CENTER)
    sleep(0.8)

    fps_frames = 0
    fps_start = time.perf_counter()
    loop_fps = 0.0

    try:
        
        tof_start_time = time.monotonic()

        while True:

            right_wall = None
            rightDzone = False

            front_frame = front_cam.capture_array()
            front_frame = cv2.cvtColor(front_frame, cv2.COLOR_RGB2BGR)

            output = front_frame.copy()
            (detections, color_detections, black_walls, pillar_detections, masks) = vision.obstacle_detections(front_frame)

            output = vision.annotate(front_frame,color_detections,black_walls,pillar_detections)
            
            current_time = time.monotonic()

            tof_start_elapsed = (current_time - tof_start_time)
            if tof_start_elapsed >= TOF_START_DELAY:
                tof_distance = TUF.tof1.range
                print(f"TOF: {tof_distance} mm | "f"Detection Count: {tof_detect_count}/2")
                if tof_distance < TOF_STOP_DISTANCE:
                    if (tof_detect_count == 0 or current_time - last_tof_detection_time >= TOF_COOLDOWN):
                        tof_detect_count += 1
                        last_tof_detection_time = (current_time)
                        print("------------------------------------------")
                        print(f"TOF DETECTION " f"#{tof_detect_count}")
                        print(f"Distance: " f"{tof_distance} mm")

                        if tof_detect_count == 1:
                            print("FIRST TOF DETECTION")
                            print("Robot will CONTINUE")
                            print(f"Cooldown started: " f"{TOF_COOLDOWN} seconds")

                        elif tof_detect_count >= 2:
                            print("SECOND TOF DETECTION")
                            print("2 detections confirmed")
                            print("TOF SECOND DETECTION " "-> ROBOT STOP")
                            drive.stop()
                            cv2.putText(output,f"TOF STOP "f"#{tof_detect_count} - "f"{tof_distance} mm",(10, HEIGHT - 45),cv2.FONT_HERSHEY_SIMPLEX,0.65,vision.WHITE,2)
                            cv2.putText(output,"2 TOF DETECTIONS -> STOP",(10, HEIGHT - 18),cv2.FONT_HERSHEY_SIMPLEX,0.55,vision.WHITE,2)
                            cv2.imshow("FRONT CAMERA - RIGHT WALL",output)
                            cv2.waitKey(1)
                            break
                        print("------------------------------------------")
                    else:
                        remaining = (TOF_COOLDOWN - (current_time - last_tof_detection_time))
                        print(f"TOF < " f"{TOF_STOP_DISTANCE} mm " f"but cooldown active | " f"{remaining:.2f}s remaining")
            else:
                tof_distance = None
                remaining_start_delay = (TOF_START_DELAY - tof_start_elapsed)
                print(f"TOF START DELAY | " f"{remaining_start_delay:.2f}s remaining")
                cv2.putText(output, f"TOF ENABLES IN: " f"{remaining_start_delay:.1f}s", (10, 90), cv2.FONT_HERSHEY_SIMPLEX, 0.55, vision.WHITE, 2)
            
            black_blob = vision.largest_detection(detections["BLACK"])
            magenta_blob = vision.largest_detection(detections["MAGENTA"])

            center_black_blob = None
            left2_black_blob = None
            right2_black_blob = None
            left1_black_blob = None
            right1_black_blob = None
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

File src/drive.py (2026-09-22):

import RPi.GPIO as GPIO
from gpiozero import RotaryEncoder
from time import sleep, monotonic

# ============================================================
# ROBOT SETTINGS
# ============================================================

# ---------------- MOTOR ----------------

PWM_PIN = 13
IN1_PIN = 5
IN2_PIN = 6

# ---------------- SERVO ----------------

SERVO_PIN = 22

CENTER = 75
LEFT = 40
RIGHT = 110

# ---------------- ENCODER ----------------

ENCODER_A_PIN = 17
ENCODER_B_PIN = 27


# ============================================================
# DRIVE SETTINGS
# ============================================================

DEFAULT_SPEED = 40

# Encoder polling
ENCODER_POLL_INTERVAL = 0.002

# Encoder print interval
ENCODER_PRINT_INTERVAL = 0.05

# Safety timeout
DEFAULT_TIMEOUT = 15.0

# Slow down near target
SLOWDOWN_STEPS = 5

# Speed near target
SLOW_SPEED = 22


# ============================================================
# GPIO SETUP
# ============================================================

GPIO.setmode(GPIO.BCM)
GPIO.setwarnings(False)

GPIO.setup(PWM_PIN, GPIO.OUT)
GPIO.setup(IN1_PIN, GPIO.OUT)
GPIO.setup(IN2_PIN, GPIO.OUT)
GPIO.setup(SERVO_PIN, GPIO.OUT)


# ============================================================
# MOTOR PWM
# ============================================================

motor_pwm = GPIO.PWM(PWM_PIN, 1000)
motor_pwm.start(0)


# ============================================================
# SERVO PWM
# ============================================================

servo_pwm = GPIO.PWM(SERVO_PIN, 50)
servo_pwm.start(0)


# ============================================================
# ENCODER
# ============================================================

encoder = RotaryEncoder(
    ENCODER_A_PIN,
    ENCODER_B_PIN,
    max_steps=0
)


# ============================================================
# SERVO
# ============================================================

def steer(angle):

    # Limit angle
    angle = max(
        LEFT,
        min(RIGHT, angle)
    )

    duty = 2.5 + (angle / 180.0) * 10.0

    servo_pwm.ChangeDutyCycle(duty)

    sleep(0.05)

    # Turn PWM signal off after movement
    servo_pwm.ChangeDutyCycle(0)


# ============================================================
# NORMAL MOTOR FORWARD
# ============================================================

def forward(speed):

    speed = max(
        0,
        min(100, speed)
    )

    GPIO.output(
        IN1_PIN,
        GPIO.LOW
    )

    GPIO.output(
        IN2_PIN,
        GPIO.HIGH
    )

    motor_pwm.ChangeDutyCycle(speed)


# ============================================================
# NORMAL MOTOR BACKWARD
# ============================================================

def backward(speed):

    speed = max(
        0,
        min(100, speed)
    )

    GPIO.output(
        IN1_PIN,
        GPIO.HIGH
    )

    GPIO.output(
        IN2_PIN,
        GPIO.LOW
    )

    motor_pwm.ChangeDutyCycle(speed)


# ============================================================
# MOTOR STOP
# ============================================================

def stop():

    motor_pwm.ChangeDutyCycle(0)


# ============================================================
# ENCODER POSITION
# ============================================================

def encoder_position():

    return int(encoder.steps)


# ============================================================
# RESET ENCODER
# ============================================================

def reset_encoder():

    encoder.steps = 0

    return encoder_position()


# ============================================================
# ENCODER BASED FORWARD
# ============================================================

def driveencoder(
    motion_steps,
    speed=DEFAULT_SPEED,
    timeout=DEFAULT_TIMEOUT
):

    """
    Move FORWARD by encoder steps.

    Example:

        driveencoder(65)

    Move forward 65 encoder steps.

    Example:

        driveencoder(100, 50)

    Move forward 100 encoder steps at speed 50.
    """

    motion_steps = int(motion_steps)
    speed = float(speed)

    if motion_steps < 0:

        raise ValueError(
            "motion_steps must be 0 or greater."
        )

    if speed <= 0 or speed > 100:

        raise ValueError(
            "speed must be between 1 and 100."
        )

    if motion_steps == 0:

        stop()

        return 0


    # --------------------------------------------------------
    # RESET ENCODER
    # --------------------------------------------------------

    reset_encoder()

    starting_position = encoder_position()

    started_at = monotonic()

    last_print_time = started_at

    current_speed = speed


    print()
    print("======================================")
    print("ENCODER FORWARD START")
    print("======================================")
    print("Target steps:", motion_steps)
    print("Motor speed:", speed)
    print("Starting encoder:", starting_position)
    print("======================================")
    print()


    try:

        # ----------------------------------------------------
        # START MOTOR
        # ----------------------------------------------------

        forward(speed)


        while True:

            current_position = encoder_position()

            progress = abs(
                current_position
                - starting_position
            )

            remaining = max(
                0,
                motion_steps - progress
            )


            # ------------------------------------------------
            # PRINT ENCODER
            # ------------------------------------------------

            current_time = monotonic()

            if (
                current_time - last_print_time
                >= ENCODER_PRINT_INTERVAL
            ):

                print(
                    "Encoder:",
                    current_position,
                    "| Progress:",
                    progress,
                    "/",
                    motion_steps,
                    "| Remaining:",
                    remaining
                )

                last_print_time = current_time


            # ------------------------------------------------
            # TARGET REACHED
            # ------------------------------------------------
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

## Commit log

2026-06-26 Add files via upload
    Adds a Raspberry Pi colour-detection script using Picamera2, OpenCV, and HSV thresholding. The program detects red, blue, green, orange, and pink objects, removes mask noise using morphological operations, and labels the largest detected colour region with a bounding box.
2026-08-17 add Raspberry Pi dependency requirements
2026-08-25 Create wiring_guide
2026-09-22 Create drivetrain
2026-09-24 Update drivetrain
